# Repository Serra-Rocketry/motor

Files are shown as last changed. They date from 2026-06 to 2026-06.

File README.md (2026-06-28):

# Motor — Serra Rocketry

Desenhos CAD, especificações e dados de testes estáticos de motores de foguetes.

## Sobre

Este repositório contém a documentação técnica dos motores desenvolvidos pela equipe Serra Rocketry (IPRJ/UERJ). Aqui ficam os desenhos de peça, montagens, simulações OpenMotor e dados brutos de testes estáticos.

> **Nota:** O sistema de aquisição de dados (firmware, hardware, calibração) fica no repositório [thrust-stand](https://github.com/Serra-Rocketry/thrust-stand). Este repo armazena apenas os dados coletados e a documentação dos motores.

## Fronteira de Responsabilidade

Este repositório (`motor`) contém a **documentação da propulsão** e é a **fonte de verdade para geometria e dados brutos de motores**.

**Este repo contém:**
- Geometria do motor (CAD: .SLDPRT, .SLDASM, .SLDDRW, .STL, .STEP)
- Dados brutos de teste estático (.txt do SD card)
- Simulações OpenMotor (.ric)
- Gráficos simples de validação (thrust/pressão x tempo)
- Imagens e GIFs de testes
- Documentação técnica dos motores (.md)

**Este repo NÃO contém:**
- Análises sofisticadas de voo → [analysis](https://github.com/Serra-Rocketry/analysis)
- Biblioteca de motores (app web) → [analysis](https://github.com/Serra-Rocketry/analysis)
- Computador de bordo → [flight-computer](https://github.com/Serra-Rocketry/flight-computer)
- Simulações de trajetória → [analysis](https://github.com/Serra-Rocketry/analysis)

**Diagrama:**
```
[motor] ──dados brutos──→ [analysis] ──→ app web, biblioteca
   │                           │
   │ Propulsão                 │ Telemetria
   │ - Geometria               │ - Análise de testes
   │ - Dados SD card           │ - Simulações de voo
   │ - CAD                     │ - Visualização
   │ - OpenMotor (.ric)        │ - Biblioteca de motores
```

## Estrutura

```
docs/
├── static-tests/          # Dados de testes estáticos
│   ├── motor-gabriel/     # Dados SD + gráfico
│   ├── motor-caramelo/
│   ├── motor-i/
│   └── scilab/            # Projetos SciLab para análise
├── motors/                # Documentação por motor
│   ├── sr21000/           # Motor principal (2025)
│   ├── sr1500/            # Motor SR1500
│   ├── 300m/              # Motor 300M
│   ├── v1/                # Motor V1.0
│   └── cardboard/         # Motor de papelão
├── rockets/               # Foguetes (não apenas motores)
│   ├── 500m/              # Foguete de 500m
│   ├── 1000m/             # Foguete de 1km
│   └── commercial/        # Foguete comercial
├── molds/                 # Moldes para propelentes
├── tools/                 # Ferramentas e gabaritos
├── archive/               # Ideias experimentais não implementadas
├── imagens/               # Fotos, renderings, gráficos
└── training/              # Documentação de treinamento
```

## Competições

| Motor | Competição | Missão | Categoria | Ano | Resultado |
|---|---|---|---|---|---|
| SR21000 | [LASC 2025](https://www.lasc.space/past-events/6th-lasc) | SR Couto | 1 km – SRM | 2025 | 11º lugar, Major Damage |

## Como Usar

### Abrir arquivos CAD

Os arquivos `.SLDPRT` e `.SLDASM` são do SolidWorks. Se não tiver SolidWorks:

- Use o [eDrawings Viewer](https://www.solidworks.com/product/edrawings-viewer) (gratuito)
- Arquivos `.STEP` abrem em qualquer CAD (FreeCAD, Fusion 360, etc.)
- Arquivos `.STL` são para impressão 3D (slicer)

### Simulações OpenMotor

Arquivos `.ric` são do [OpenMotor](https://github.com/reilleya/openMotor), software livre de simulação de motores de foguete. Para abrir:

1. Instale o OpenMotor: `pip install openmotor` ou baixe o executável
2. Abra o arquivo `.ric` correspondente ao motor
3. Execute a simulação

### Dados de Teste

Os arquivos `.txt` em `static-tests/` contêm dados brutos do SD card no formato:

```
HH:MM:SS ; empuxo(kN) ; tempo(ms)
```

## Contribuindo

Este projeto segue as [Boas Práticas da Serra Rocketry](https://github.com/Serra-Rocketry/best-practices). Para contribuir:

1. Fork o projeto
2. Crie uma branch (`git checkout -b feature/nome`)
3. Commit suas mudanças
4. Abra um Pull Request

### Regras para Arquivos CAD

- Normalizar nomes: sem acentos, espaços → `_`
- SolidWorks 2024+ (compatível com versões anteriores)
- Incluir desenhos técnicos (`.SLDDRW`) quando disponível
- Exportar `.STEP` para interoperabilidade

## Links

- [Thrust Stand](https://github.com/Serra-Rocketry/thrust-stand) — Sistema de aquisição de dados
- [Ignitor](https://github.com/Serra-Rocketry/ignitor) — Sistema de ignição remota
- [Best Practices](https://github.com/Serra-Rocketry/best-practices) — Boas práticas da equipe
- [MIGRATION.md](./MIGRATION.md) — Histórico de migração do Drive

---

**Mantido por:** Equipe Serra Rocketry — IPRJ/UERJ

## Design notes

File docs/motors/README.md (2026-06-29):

# Motores

Documentação CAD e especificações dos motores desenvolvidos pela Serra Rocketry.

## Motores

| Motor | Status | Propulsante | Empuxo | Arquivos |
|---|---|---|---|---|
| [SR21000](./sr21000/) | Concluído | KNSU | 21000 Ns | CAD, desenhos, OpenMotor, STL, Parasolid |
| [SR1500](./sr1500/) | Concluído | KNSU | 1500 Ns | CAD, desenhos, OpenMotor, STL, gcode |
| [300M](./300m/) | Concluído | KNSU | — | CAD, STL, gcode |
| [V1](./v1/) | Concluído | KNSU | — | CAD |
| [Cardboard](./cardboard/) | Concluído | KNSU | — | CAD, STL (moldes) |

## Estrutura por motor

Cada motor pode ter as seguintes subpastas:

| Subpasta | Conteúdo | Software |
|---|---|---|
| `cad/` | Peças (`.SLDPRT`) e montagens (`.SLDASM`) | SolidWorks |
| `drawings/` | Desenhos técnicos (`.SLDDRW`, `.pdf`) | SolidWorks |
| `openmotor/` | Simulações (`.ric`) | [OpenMotor](https://github.com/reilleya/openMotor) |
| `stl/` | Modelos para impressão 3D (`.STL`) | Slicer |
| `parasolid/` | Modelos Parasolid (`.x_t`) | Interop CAD |
| `gcode/` | Instruções de impressão 3D (`.gcode`) | Slicer |

## Como abrir os arquivos

- **SolidWorks** (`.SLDPRT`, `.SLDASM`, `.SLDDRW`): SolidWorks 2024+ ou [eDrawings Viewer](https://www.solidworks.com/product/edrawings-viewer) (gratuito)
- **STEP** (`.step`, `.STEP`): qualquer CAD (FreeCAD, Fusion 360, SolidWorks)
- **STL** (`.STL`): qualquer slicer de impressão 3D
- **OpenMotor** (`.ric`): [OpenMotor](https://github.com/reilleya/openMotor) — software livre de simulação
- **Parasolid** (`.x_t`): SolidWorks, Fusion 360, ou qualquer CAD que suporte o formato

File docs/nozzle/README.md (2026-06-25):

# Nozzle de Cimento

Projeto do nozzle de cimento para motores de foguete.

## Arquivos

### CAD

| Arquivo | Descrição |
|---|---|
| [Base_Molde.SLDPRT](./cad/Base_Molde.SLDPRT) | Base do molde |
| [Meio_1_Molde.SLDPRT](./cad/Meio_1_Molde.SLDPRT) | Parte intermediária 1 |
| [Meio_2_Molde.SLDPRT](./cad/Meio_2_Molde.SLDPRT) | Parte intermediária 2 |
| [Topo_Molde.SLDPRT](./cad/Topo_Molde.SLDPRT) | Topo do molde |

### Montagem

| Arquivo | Descrição |
|---|---|
| [Montagem_Nozzle.SLDASM](./assembly/Montagem_Nozzle.SLDASM) | Montagem completa do nozzle |

### Cálculos

| Arquivo | Descrição |
|---|---|
| [calculo_nozzle.ipynb](./notebook/calculo_nozzle.ipynb) | Jupyter notebook com cálculos de nozzle |
| [passos_a_seguir.png](./passos_a_seguir.png) | Fluxograma de fabricação |

## Como usar

1. Abra os arquivos `.SLDPRT` no SolidWorks ou eDrawings
2. Para os cálculos, abra o notebook no Jupyter: `jupyter notebook calculo_nozzle.ipynb`

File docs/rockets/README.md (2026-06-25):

# Foguetes

Documentação CAD dos foguetes da Serra Rocketry.

## Foguetes

| Foguete | Altitude | Motor | Status | Arquivos |
|---|---|---|---|---|
| [500m](./500m/) | 500m | SR500M | Em desenvolvimento | CAD, STEP, montagem, OpenMotor |
| [1000m](./1000m/) | 1000m | SR1000M | Em desenvolvimento | CAD, STEP, montagem, OpenMotor |
| [Commercial](./commercial/) | — | — | — | CAD, STL, gcode |

## Estrutura por foguete

| Subpasta | Conteúdo |
|---|---|
| `cad/` | Peças (`.SLDPRT`) |
| `assembly/` | Montagens (`.SLDASM`) |
| `step/` | Modelos STEP para interoperabilidade |
| `parasolid/` | Modelos Parasolid (`.x_t`) |
| `simulation/` | Análises de simulação |
| `openmotor/` | Simulações do motor (`.ric`) |
| `mold/` | Moldes (`.step`) |

## Documentação

- [Documentação do foguete de 500m](./500m/documentation.md)
- [Documentação do foguete de 1km](./1000m/documentation.md)
- [Teste hidrostático do foguete de 500m](./500m/TESTE_HIDROSTATICO_500m_62bar.xls)

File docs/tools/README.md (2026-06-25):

# Ferramentas e Gabaritos

Ferramentas e gabaritos utilizados na fabricação de motores.

## Arquivos

### CAD

| Arquivo | Descrição |
|---|---|
| [Guia_Furo_Alma_Motor_De_Teste.SLDPRT](./cad/Guia_Furo_Alma_Motor_De_Teste.SLDPRT) | Guia para furo da alma do motor |

### STL (impressão 3D)

| Arquivo | Descrição |
|---|---|
| [Guia_Furo_Alma_Motor_De_Teste.STL](./stl/Guia_Furo_Alma_Motor_De_Teste.STL) | Guia para furo (imprimível) |

### G-code

| Arquivo | Material | Descrição |
|---|---|---|
| [CE3E3V2_Guia_Furo_Alma_Motor_De_Teste_PLA.gcode](./gcode/CE3E3V2_Guia_Furo_Alma_Motor_De_Teste_PLA.gcode) | PLA | Guia para furo |
| [CE3E3V2_Guia_Furo_Alma_Motor_De_Teste_PETG.gcode](./gcode/CE3E3V2_Guia_Furo_Alma_Motor_De_Teste_PETG.gcode) | PETG | Guia para furo |
| [Guia_Filamento_PLA.gcode](./gcode/Guia_Filamento_PLA.gcode) | PLA | Guia de filamento |

## Impressão 3D

Os arquivos `.gcode` são para impressora Ender 3 (CE3). Para usar em outra impressora, abra o `.STL` no seu slicer e gere o gcode correspondente.

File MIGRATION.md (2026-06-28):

# Migração do Drive para Git

## Origem

- **Fonte:** Google Drive, pasta "3-Propulsão"
- **Data da exportação:** 24/06/2026
- **Formato:** 3 arquivos ZIP (`3-Propulsão-20260624T230916Z-3-001.zip`, `-002`, `-003`)
- **Total:** ~5.4 GB, 390 arquivos
- **Backup local:** pasta `drive/` (não versionada, mantida como referência)

## Regras de Normalização

Nomes de arquivos e pastas foram normalizados para compatibilidade com Git:

- Acentos removidos: `ã→a`, `ç→c`, `é→e`, `ó→o`, `í→i`, `ú→u`
- Espaços → `_`
- Parênteses removidos
- Maiúsculas/minúsculas mantidas
- Exemplo: `Restrição_motor.SLDPRT` → `Restricao_motor.SLDPRT`

---

## Batch 1 — Estrutura e CAD (24/06/2026)

### Copiado

| Origem no Drive | Destino no Repo | Qtd |
|---|---|---|
| `Dados Testes Estático/Dados SDcard/MotorGabriel.txt` | `docs/static-tests/motor-gabriel/data.txt` | 1 |
| `Dados Testes Estático/Dados SDcard/MotorCaramelo.txt` | `docs/static-tests/motor-caramelo/data.txt` | 1 |
| `Dados Testes Estático/Gráficos/Motor I (69-31...).jpg` | `docs/static-tests/motor-i/empuxo_pressao.jpg` | 1 |
| `Dados Testes Estático/Gráficos/Motor Caramelo (65-35).jpg` | `docs/static-tests/motor-caramelo/empuxo_pressao.jpg` | 1 |
| `Dados Testes Estático/Gráficos/*.sciprj` | `docs/static-tests/scilab/` | 2 |
| `Motor SR1500/Componentes/` | `docs/motors/sr1500/cad/` | 8 |
| `Motor SR1500/Openmotor e Desenhos Técnicos/` | `docs/motors/sr1500/drawings/` | 3 |
| `Motor SR1500/Openmotor e Desenhos Técnicos/Motor SR1500.ric` | `docs/motors/sr1500/openmotor/` | 1 |
| `Motor SR1500/Componentes/GUIAALMA10MM.STL` | `docs/motors/sr1500/stl/` | 1 |
| `Motor SR1500/Componentes/CE3E3V2_GUIAALMA10MM.gcode` | `docs/motors/sr1500/gcode/` | 1 |
| `Motor SR1500/O_Ring .jpeg` | `docs/motors/sr1500/images/o_ring.jpg` | 1 |
| `SR21000/` (top-level CAD) | `docs/motors/sr21000/cad/` | 21 |
| `SR21000/Desenhos Tecnicos/` | `docs/motors/sr21000/drawings/` | 6 |
| `SR21000/*.ric` | `docs/motors/sr21000/openmotor/` | 3 |
| `SR21000/Inibidor/MoldeInibidor.STL` + `Fotos/Nozzle.STL` | `docs/motors/sr21000/stl/` | 2 |
| `SR21000/*.x_t` | `docs/motors/sr21000/parasolid/` | 3 |
| `SR21000/Inibidor/CE3E3V2_MoldeInibidor.gcode` | `docs/motors/sr21000/gcode/` | 1 |
| `SR21000/Molde Prensagem/` | `docs/motors/sr21000/cad/` | 2 |
| `SR21000/Fotos e Informações/*.jpg` | `docs/motors/sr21000/images/` | 2 |
| `SR21000/Fotos e Informações/captura*.png` | `docs/motors/sr21000/images/capturas/` | 4 |
| `SR21000/Teste Hidrostático/Gráfico_*.png` | `docs/motors/sr21000/images/` | 1 |
| `Motor SR21000 Inicial/` CAD | `docs/motors/sr21000-initial/cad/` | 4 |
| `Motor SR21000 Inicial/*.ric` | `docs/motors/sr21000-initial/openmotor/` | 2 |
| `Motor SR21000 Inicial/Fotos/` | `docs/imagens/sr21000-initial/` | 6 |
| `Dados e Testes Antigos/Motor 300M/` CAD | `docs/motors/300m/cad/` | 6 |
| `Dados e Testes Antigos/Motor 300M/*.STL` | `docs/motors/300m/stl/` | 2 |
| `Dados e Testes Antigos/Motor 300M/*.gcode` | `docs/motors/300m/gcode/` | 1 |
| `Dados e Testes Antigos/Motor V1.0/` CAD | `docs/motors/v1/cad/` | 4 |
| `Dados e Testes Antigos/Motor Papelão/` | `docs/motors/cardboard/` | 9 |
| `2026/Foguete 500M/` | `docs/rockets/500m/` | 10 |
| `2026/Foguete 1000M/` | `docs/rockets/1000m/` | 17 |
| `2025/Foguete Comercial/` | `docs/rockets/commercial/` | 3 |
| `2026/Molde/` | `docs/molds/` | 3 |
| `2025/Ideias/Molde Nozzle Cimento/` | `docs/nozzle/` | 9 |
| `2025/Ferramentas/` | `docs/tools/` | 6 |
| `2025/Código Nozzle/Calculo_Nozzle.ipynb` | `docs/nozzle/notebook/` | 1 |
| `2025/Código Nozzle/Passos a Seguir.png` | `docs/nozzle/` | 1 |

### docx → md (conversões)

| docx original | Destino |
|---|---|
| `Dimensões 1° motor.docx` | `docs/motors/v1/dimensoes.md` |
| `Tampa Motor.docx` | `docs/motors/v1/tampa_motor.md` |
| `Relatório SR21000.docx` | `docs/motors/sr21000/report.md` |
| `Anotações Caio.docx` | `docs/motors/sr21000/notes.md` |
| `Passos a Seguir Projeto SR 21000.docx` | `docs/motors/sr21000/next_steps.md` |
| `Materiais a ser utilizado.docx` | `docs/motors/sr21000-initial/materials.md` |
| `Pino_ParafusoSim-Análise estática 1-1.docx` | `docs/motors/sr21000/pin_analysis.md` |
| `Tubo-Teste De Pressão Interna Tubo-1.docx` | `docs/motors/sr21000/tube_pressure_test.md` |
| `Tubo-Análise estática 2-1.docx` | `docs/motors/sr21000/tube_analysis.md` |
| `Descrição Das Tarefas.docx` | `docs/training/task_description.md` |

### Ignorados (para processar depois)

| Item | Tamanho | Motivo | Próximo passo |
|---|---|---|---|
| `Eletrônica/` CAD | ~49 MB | Pertence ao thrust-stand | Mover para Serra-Rocketry/thrust-stand |
| `testeestatico/` STEP | ~0.1 MB | Bancada de teste, não motor | Vai para thrust-stand |
| Vídeos (.MOV/.MP4/.avi) | ~4.5 GB | Muito grandes para git | Batch 3: converter selecionados em GIFs |
| `.CWR` simulações | ~216 MB | Regeneráveis no SolidWorks | Ignorar permanentemente |
| `openMotor.exe` | 69 MB | Binário de terceiros | Ignorar (linkar download no README) |
| `.dmp`, `.err`, `.LOG`, `.MFC`, `.BMC`, `.BD2`, `.BDF`, `.PGF` | ~0.5 MB | Lixo de IDE/simulação | Ignorar permanentemente |
| `Reuniões/` (docx + png) | ~0.01 MB | Notas de reunião | ✅ Batch 2: convertido para md |
| `Fotos HEIC` (testes de queima, estufa) | ~44 MB | Formato Apple, precisa converter | Batch 3: converter para jpg |
| `Testes Propelente/` (docx + fotos + xlsx) | ~8.8 MB | Documentação de propelentes | ✅ Batch 2: copiado para propellants/ |
| `Dados Testes Estático/Dados SDcard/Motor6535.txt` | 34 B | Conteúdo: "Não Conseguimos Obter Os Dados :(" | Ignorar |
| `Dados Testes Estático/Dados SDcard/MotorÓxidoDeFerroeMagnésio.txt` | 31 B | Conteúdo: "Não Conseguimos Pegar Dados :(" | Ignorar |
| `SR21000/Teste Hidrostático/Mídias/` (vídeos) | ~340 MB | Vídeos de teste hidrostático | Batch 3: converter selecionados |
| `Motor SR21000 Inicial/` docx (relatório, anotações, etc.) | ~5 MB | Duplicata do SR21000 | Já copiado via SR21000 |
| `Fotos e Informações/Mont1.avi` | ~5 MB | Vídeo de montagem | Batch 3 |
| `Desenhos Tecnicos/*.PNG` (renderings) | ~0.3 MB | Imagens de referência | Já copiado em imagens/ |
| `.sciprj` (SciLab projects) | ~0.7 MB | Projetos SciLab | Já copiado em scilab/ |

---

## Batch 2 — Documentação restante (24/06/2026)

### docx → md

| docx original | Destino |
|---|---|
| `SR21000/Teste Hidrostático/Descrição do Teste.docx` | `docs/motors/sr21000/hydrostatic_test_description.md` |
| `Motor SR21000 Inicial/Simulações/Case do motor/Tubo-Teste De Pressão Interna Tubo-1.docx` | `docs/motors/sr21000-initial/tube_pressure_simulation.md` |
| `Testes Propelente/Teste Granulometria.../Descrição Do Teste.docx` | `docs/propellants/granulometry_test_description.md` |
| `Reuniões/Reunião Dia 09_08_2024.docx` | `docs/meetings/2024-08-09.md` |
| `Reuniões/Reunião 06_02_2026 (Caio e Italo).docx` | `docs/meetings/2026-02-06.md` |
| `2026/Foguete 1000M/Documentação.docx` | `docs/rockets/1000m/documentation.md` |
| `2026/Foguete 500M/Documentação do motor de 500m.docx` | `docs/rockets/500m/documentation.md` |
| `2026/Eletrônica/Ignitor/Funcionamento.docx` | `docs/ignitor/funcionamento.md` |
| `Teste De Queima 09-06-2023/Propelentes.docx` | `docs/propellants/teste_queima_2023-06-09.md` |
| `2026/Ideias.docx` | `docs/ideas.md` |

### Arquivos copiados

| Arquivo | Destino |
|---|---|
| `SR21000/Teste Hidrostático/*.xlsx` | `docs/motors/sr21000/TESTE_HIDROSTATICO_SR21000_88bar.xlsx` |
| `SR21000/Bulkhead_Sensor_Pressão.pdf` | `docs/motors/sr21000/drawings/Bulkhead_Sensor_Pressao.pdf` |
| `Foguete 500M/Teste Hidrostático/*.xls` | `docs/rockets/500m/TESTE_HIDROSTATICO_500m_62bar.xls` |
| `Teste De Queima/Dados Propelentes.xlsx` | `docs/propellants/dados_propelentes.xlsx` |
| `Teste Reprodutibilidade/*.xlsx` | `docs/propellants/teste_reprodutibilidade.xlsx` |
| `Teste estufa/planilha_teste_estufa.xlsx` | `docs/propellants/planilha_teste_estufa.xlsx` |
| `Ignitor/*.pdf` (fluxogramas) | `docs/ignitor/` |
| `Ignitor/README.md` | `docs/ignitor/README.md` |
| `Reunião Dia 16-05-2025/*.png` | `docs/meetings/images/` |
| `Reunião Dia 16-05-2025/*.ric` | `docs/meetings/` |
| `SR21000/Teste Hidrostático/Mídias/` (fotos) | `docs/motors/sr21000/images/hydrostatic/` |
| `Propelentes.jpeg` (foto) | `docs/propellants/photos/` |

### Novas pastas criadas

- `docs/propellants/` — documentação e dados de propelentes
- `docs/meetings/` — notas de reunião
- `docs/ignitor/` — documentação do ignitor (pertence ao thrust-stand)
- `docs/motors/sr21000/images/hydrostatic/` — fotos do teste hidrostático

---

## Batch 3 — GIFs de testes de queima (25/06/2026)

### Vídeos convertidos para GIF (320px, 8fps)

10 vídeos do teste de queima 09/06/2023 convertidos para GIF. Vídeos originais (~2.1 GB) mantidos apenas no `drive/`.

| Vídeo original | GIF | Tamanho |
|---|---|---|
| `Propelente 1 - 65% Nitrato 35% Açúcar.MOV` | `prop_1_knsu_padrao.gif` | 25 MB |
| `Propelente 2 - 65% Nitrato 35% Açúcar.MOV` | `prop_2_knsu_coroa.gif` | 13 MB |
| `Propelente 3 - 70% Nitrato 30% Açúcar.MOV` | `prop_3_knsu_70_30.gif` | 13 MB |
| `Propelente 4 - 50% Nitrato 50% Açúcar.MOV` | `prop_4_50_50.gif` | 32 MB |
| `Propelente 5 - 65% Nitrato 35% Dextrose.MOV` | `prop_5_knd.gif` | 13 MB |
| `Dextrose part 2.MOV` | `prop_5b_dextrose_part2.gif` | 4,5 MB |
| `Propelente 7 - ...CuFe2O4.MOV` | `prop_7_cufe2o4.gif` | 9,8 MB |
| `Propelente 8 - ...CoFe2O4.MOV` | `prop_8_cofe2o4.gif` | 20 MB |
| `Propelente 9 - ...NiFe2O4.MOV` | `prop_9_nife2o4.gif` | 14 MB |
| `Propelente 10 - ...ZnFe2O4.MOV` | `prop_10_znfe2o4.gif` | 14 MB |

**Total GIFs:** 155 MB (vs ~2.1 GB originais)

### Documentação atualizada

- `docs/propellants/teste_queima_2023-06-09.md` — reescrito com tabela, GIFs embutidos e links para dados
- Issue #1 criada: esclarecer diferença do Propelente 2 ("jeito do coroa")

### Vídeos ignorados (mantidos no drive/)

| Grupo | Tamanho | Motivo |
|---|---|---|
| Teste De Queima 10-07-2023 (5 vídeos) | ~560 MB | Sem nomes, sem documentação |
| Teste estufa (~35 vídeos) | ~1.9 GB | Sem nomes descritivos |
| Reunião OpenMotor.mp4 | 145 MB | Gravação de reunião |

## Batch 4 — Finalização (25/06/2026)

### READMEs criados

| Arquivo | Descrição |
|---|---|
| `docs/motors/README.md` | Visão geral dos motores e estrutura por motor |
| `docs/rockets/README.md` | Visão geral dos foguetes |
| `docs/propellants/README.md` | Documentação de propelentes e testes |
| `docs/static-tests/README.md` | Dados de testes estáticos e formato dos dados |
| `docs/nozzle/README.md` | Projeto do nozzle de cimento |
| `docs/tools/README.md` | Ferramentas e gabaritos |

### Revisão geral

- Estrutura verificada: 208 arquivos em 65 diretórios
- 27 arquivos Markdown (docs + READMEs)
- 11 simulações OpenMotor (.ric)
- Todos os nomes de arquivos normalizados
- `.gitignore` funcionando (drive/ não versionado)

---

## Status Final

| Batch | Commit | Arquivos | Conteúdo | Data |
|---|---|---|---|---|
| 1 | `b455cda` | 152 | Estrutura + CAD + test data | 24/06/2026 |
| 2 | `6f28990` | 46 | docx→md + planilhas + fotos | 24/06/2026 |
| 3 | `5bce81e` | 12 | GIFs de testes de queima | 25/06/2026 |
| 4 | — | 7 | READMEs + revisão | 25/06/2026 |
| **Total** | | **217** | | |

### Itens restantes no drive/ (não versionados)

| Item | Tamanho | Ação futura |
|---|---|---|
| Teste De Queima 10-07-2023 (5 vídeos) | ~560 MB | Ignorar (sem documentação) |
| Teste estufa (~35 vídeos) | ~1.9 GB | Ignorar (sem nomes) |
| Reunião OpenMotor.mp4 | 145 MB | Ignorar |
| Eletrônica/ CAD | ~49 MB | Mover para thrust-stand |
| testeestatico/ STEP | ~0.1 MB | Mover para thrust-stand |

### Próximos passos (opcional)

- Converter fotos HEIC → JPG (batch futuro, se necessário)
- Adicionar dados dos testes de queima 10-07-2023 quando documentação estiver disponível
- Mover arquivos de Eletrônica para o repositório thrust-stand

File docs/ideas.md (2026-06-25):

Ideias Para Propulsão - 2026

Motor:
Testar Diferentes tipos de acoplamento bulkhead/tubo nozzle/bulkhead;
Pesquisar outros tipos de vedação e etc;
Materiais diferentes;
Designs diferentes.

Propelente:
Novas composições (Nitrato+Eritritol, RNX, Nitrato+Açucar+aditivo, Nitrato+Sorbitol+Aditivo, …);
Testar outros métodos de fabricação;
Testar outras geometrias de alma (Teflon , Nylon);
Testar diferentes moldes e inibidores.

Skib (Testar ideia do gemini)

Eletrônicos:
Ignitor com sistema de acionamento seguro e de fácil uso;
Controle de temperatura com PID para panela;
Sensor de pressão made by serra rocketry;
Teste estático oficial;
Teste estático para motores pequenos;
Moinho de bolas com controle de velocidade e tempo.

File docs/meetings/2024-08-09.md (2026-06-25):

Reunião De Nivelamento Do Projeto

Tópicos Abordados:

Tarefas constantes do setor de propulsão
Comentar sobre o foco desse período 2024.2
Desenvolver motor para teste de propelente
Teste de armazenamento squib
Testes de novas composições para squib
Testes de novas composições de propelente (tarefa constante)
Inserção do propelente no OpenMotor
Aprofundar no estudo de nozzle

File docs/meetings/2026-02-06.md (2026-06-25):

Prioridades (Eletrônica):

Ignitor (Começar nas férias - Terminar até 10/04)
Fluxograma De Funcionamento (até 25/02)- Todos
Esquemático e Lista BOM (até 09/03)- ítalo, Steffany e Dias
Desenvolvimento do código (até 25/03)- Steffany e Dias
Protótipo e Teste (até 27/03)- ítalo e Joana
Montar a PCB (até 03/04)- Caio e Joana
Desenhar a case (até 10/04)- Ítalo
Imprimir a case e montar (até 15/04)- italo
Teste Final (até 17/04)- Todos

Teste Estático Motores Pequenos (Começar e terminar nas férias)
Verificar estrutura atual
Esquemático e Lista BOM
Ajustes no código
Estrutura para fixar os motores
Protótipo
Montar a PCB
Desenhar a case
Imprimir a case e montar

Teste Estático Motores Brutos ()
Verificar estrutura atual (Eletrônica) (Até 13/03)- Todos
Esquemático e Lista BOM (Até 20/03)-Ítalo e Dias
Ajustes no código (Até 27/03)- Steffany e Dias
Projeto Em CAD (Até 03/04)- Caio e Joana
Teste Eletrônica (Até 10/04)- Ítalo
Montar a PCB (Até 03/04)-Caio e joana
Desenhar a case (Até 10/04)- Caio
Imprimir a case e montar (Até 17/04)- Caio
Montar a Estrutura (Até 01/05)- Todos
Testar (Até 18/05)- Todos

Prioridades (Propulsão):

Segurança

Regras no lab de reações (Criar Regras)
Procedimento em testes e lançamentos (Criar Procedimentos)
Procedimentos de transporte e armazenamento de inflamáveis

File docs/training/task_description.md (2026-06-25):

Tarefa 1 :  Projetar um motor no OpenMotor com as configurações definidas abaixo.

O objetivo dessa tarefa é a compreensão dos parâmetros necessários para projetar um motor , tendo noção de qual parâmetro alterar para conseguir determinadas características como curva de empuxo, pressão máxima e etc .

*Manter os Parâmetros Grifados*

Configurações de Nozzle:

Configurações do Grão do Propelente:

Propelente utilizado :

Configurações Gerais:

O Que Precisa Fazer ??

Alterar os parâmetros livres , com o objetivo de obter o maior pico de empuxo e o maior impulso total sem extrapolar a pressão máxima de 700 Psi .

Tarefa 2 :  Projetar o motor estudado no OpenMotor em CAD
( Solidworks , FreeCAD , OnShape , …).

Data Limite :

Link SolidWorks Piratão :

magnet:?xt=urn:btih:3AC3CC164166C96B95B1288627EAA089F8B530AC&dn=SolidWorks+2023+SP5+Full+Premium+%28x64%29+-+%5BhaxNode%5D&tr=http%3A%2F%2Fp4p.arenabg.com%3A1337%2Fannounce&tr=udp%3A%2F%2F47.ip-51-68-199.eu%3A6969%2Fannounce&tr=udp%3A%2F%2F9.rarbg.me%3A2780%2Fannounce&tr=udp%3A%2F%2F9.rarbg.to%3A2710%2Fannounce&tr=udp%3A%2F%2F9.rarbg.to%3A2730%2Fannounce&tr=udp%3A%2F%2F9.rarbg.to%3A2920%2Fannounce&tr=udp%3A%2F%2Fopen.stealth.si%3A80%2Fannounce&tr=udp%3A%2F%2Fopentracker.i2p.rocks%3A6969%2Fannounce&tr=udp%3A%2F%2Ftracker.coppersurfer.tk%3A6969%2Fannounce&tr=udp%3A%2F%2Ftracker.cyberia.is%3A6969%2Fannounce&tr=udp%3A%2F%2Ftracker.dler.org%3A6969%2Fannounce&tr=udp%3A%2F%2Ftracker.internetwarriors.net%3A1337%2Fannounce&tr=udp%3A%2F%2Ftracker.leechers-paradise.org%3A6969%2Fannounce&tr=udp%3A%2F%2Ftracker.openbittorrent.com%3A6969%2Fannounce&tr=udp%3A%2F%2Ftracker.opentrackr.org%3A1337&tr=udp%3A%2F%2Ftracker.pirateparty.gr%3A6969%2Fannounce&tr=udp%3A%2F%2Ftracker.tiny-vps.com%3A6969%2Fannounce&tr=udp%3A%2F%2Ftracker.torrent.eu.org%3A451%2Fannounce

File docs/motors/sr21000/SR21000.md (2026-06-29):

# Motor SR21000

**Equipe:** Serra Rocketry — IPRJ/UERJ  
**Classificação:** I254  
**Status:** Concluído

---

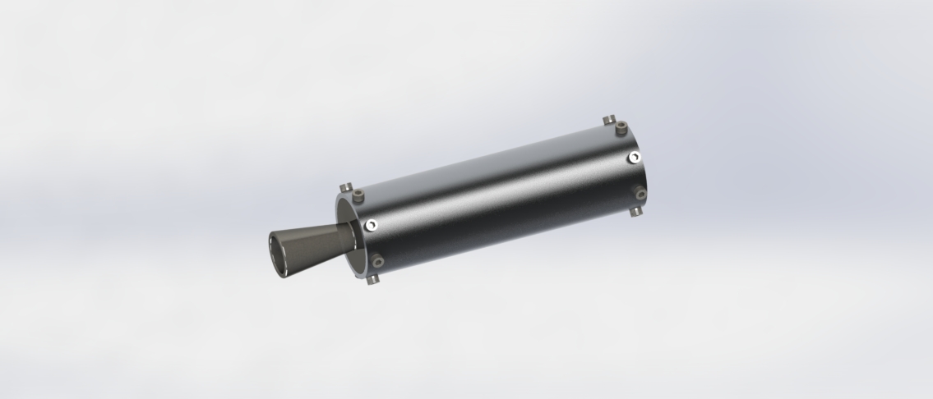
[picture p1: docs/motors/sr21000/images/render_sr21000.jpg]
Render do motor SR21000


O SR21000 é o motor principal da Serra Rocketry, projetado para atingir alturas na faixa de 1000 metros com foguetes de médio porte. Batizado em homenagem ao laboratório do IPRJ, este motor representa a evolução de anos de experimentos com propelentes sólidos — desde os primeiros grãos de KNSU caseiros até um projeto completo, simulado, fabricado, testado e最终mente levado ao voo.

Este documento conta a história completa do SR21000: como surgiu a ideia, como foi simulado no OpenMotor, como cada peça foi projetada e fabricada, como o motor se comportou sob pressão no teste hidrostático, e como ele se saiu no seu primeiro (e único) voo.

---

## Sumário

1. [Simulação OpenMotor](#simulação-openmotor)
2. [Projeto e Materiais](#projeto-e-materiais)
3. [Teste Hidrostático](#teste-hidrostático)
4. [Teste Estático](#teste-estático)
5. [Voo](#voo)
6. [Arquivos do Projeto](#arquivos-do-projeto)
7. [Dados Faltando](#dados-faltando)

---

## Simulação OpenMotor

Todo motor de foguete sólido começa no papel — ou melhor, no software. Antes de cortar qualquer tubo de alumínio ou fundir propelente, precisávamos responder perguntas fundamentais: quanto de empuxo esse motor vai gerar? Qual vai ser a pressão máxima dentro da câmara? O nozzle vai suportar?

Usamos o [OpenMotor](https://github.com/reilleya/openMotor), um software de simulação de motores de foguete sólidos, para responder essas perguntas. Duas simulações foram realizadas com propelente **Nakka KNSU** (65% KNO₃ + 35% Sacarose), utilizando os parâmetros de taxa de queima do próprio Nakka:

| Parâmetro | Valor |
|---|---|
| Coeficiente de queima (a) | 0.0001007 |
| Expoente de pressão (n) | 0.319 |
| Razão de calores específicos (k) | 1.133 |
| Temperatura de combustão (T) | 1720 K |
| Densidade do propelente | 1800 kg/m³ |

### Configuração do Grão

O grão de propelente segue a configuração **BATES** (Bulkhead Assembly with Throat and End Segments), que é o padrão para motores amadores de médio porte:

| Parâmetro | Valor |
|---|---|
| Tipo | BATES |
| Diâmetro externo | 44 mm |
| Diâmetro do core | 10 mm |
| Comprimento | 110 mm |
| Extremidades inibidas | Não |

### Da Ideia Inicial à Configuração Final

A primeira simulação — chamada "Ideia Inicial" — representava nosso chute inicial: um nozzle com throat de 8 mm e exit de 14 mm, com ângulos de convergência e divergência que seguiam referências da literatura. Mas quando analisamos os resultados, percebemos que precisávamos de mais empuxo e uma expansão mais eficiente dos gases.

A configuração final, batizada de "Nozzle SR21000", trouxe mudanças significativas:

| Parâmetro | Ideia Inicial | Nozzle SR21000 |
|---|---|---|
| Throat | 8.00 mm | 9.92 mm |
| Exit | 14.00 mm | 28.00 mm |
| Ângulo convergente | 20° | 30° |
| Ângulo divergente | 17° | 17° |

O throat maior (9.92 mm) permite uma taxa de queima mais controlada, enquanto o exit quase o dobro (28 mm) aumenta significativamente a razão de expansão — de 3.06 para 7.91 — resultando em melhor aproveitamento da energia dos gases de exaustão.

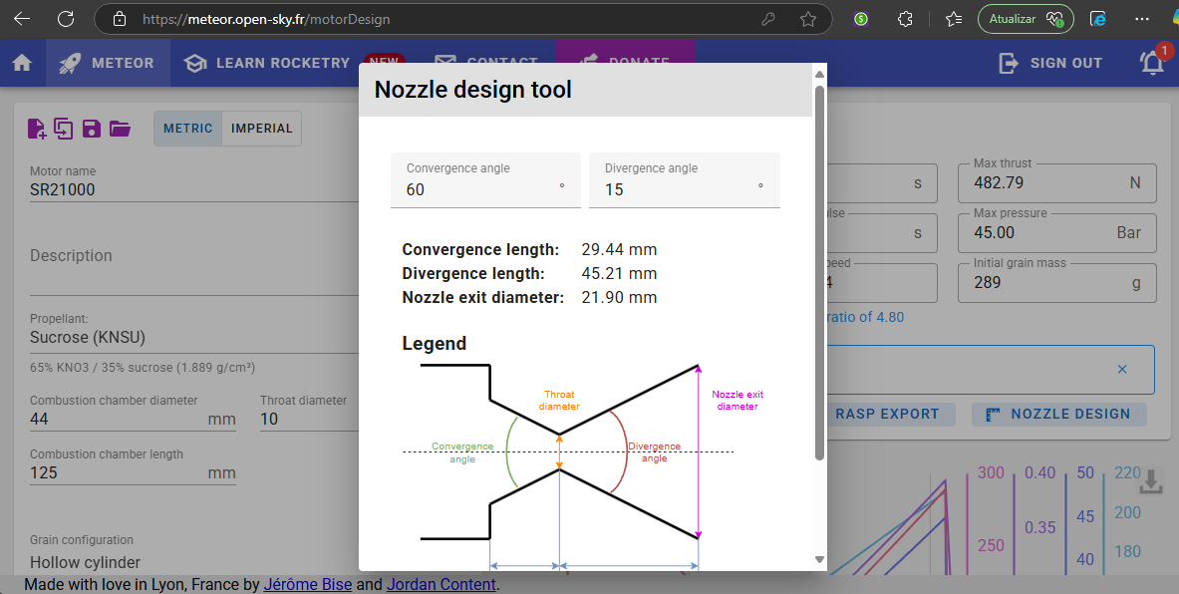
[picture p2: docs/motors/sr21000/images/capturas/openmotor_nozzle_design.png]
OpenMotor — design do nozzle


*Geometria do nozzle na simulação: seção convergente (30°), gargalo de 9.92 mm e seção divergente (17°) expandindo até 28 mm.*

### Resultados da Simulação Final

A simulação do "Nozzle SR21000" produziu os seguintes resultados:

| Parâmetro | Valor |
|---|---|
| Classificação | I254 |
| Empuxo máximo | 482.79 N |
| Impulso total | 340.95 Ns |
| Impulso específico (Isp) | 120.15 s |
| Pressão máxima | 45.00 bar |
| Pressão média | 25.34 bar |
| Tempo de queima | 1.34 s |
| Velocidade de saída | Mach 2.64 |
| Razão de expansão | 4.80 |
| Massa do grão | 289 g |

Esses números contam uma história interessante: um motor compacto, com menos de 1.1 kg no total, capaz de gerar quase 50 kg de força por mais de um segundo. A pressão máxima de 45 bar ficou bem dentro dos limites seguros para um case de alumínio — mas precisávamos confirmar isso com um teste real.

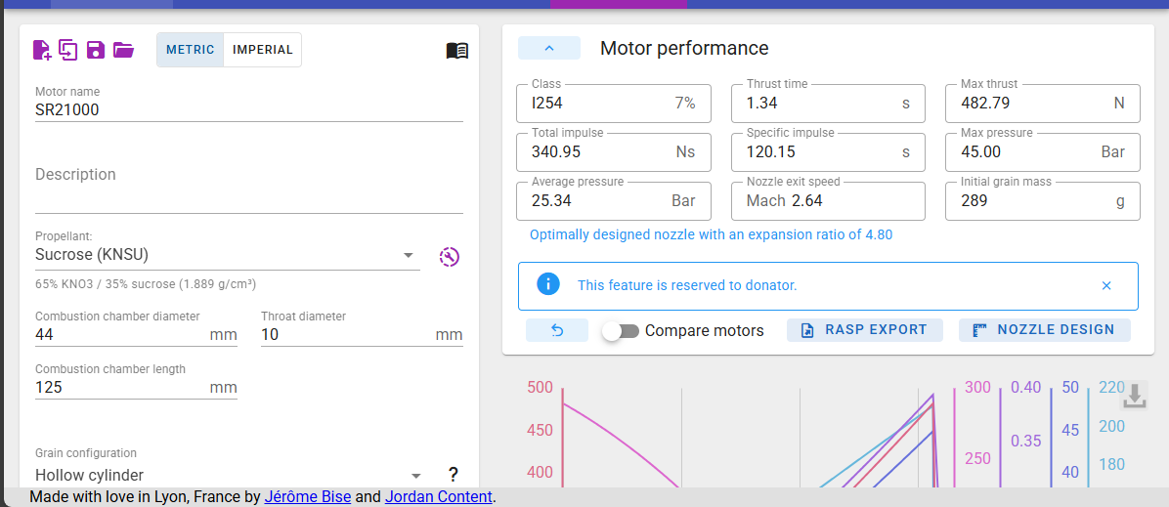
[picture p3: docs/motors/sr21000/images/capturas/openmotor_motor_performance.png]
OpenMotor — performance do motor


*Visão geral do desempenho: impulso específico, eficiência do nozzle e parâmetros de combustão.*

### Curvas de Desempenho

As simulações geraram gráficos detalhados da evolução do motor durante a queima:

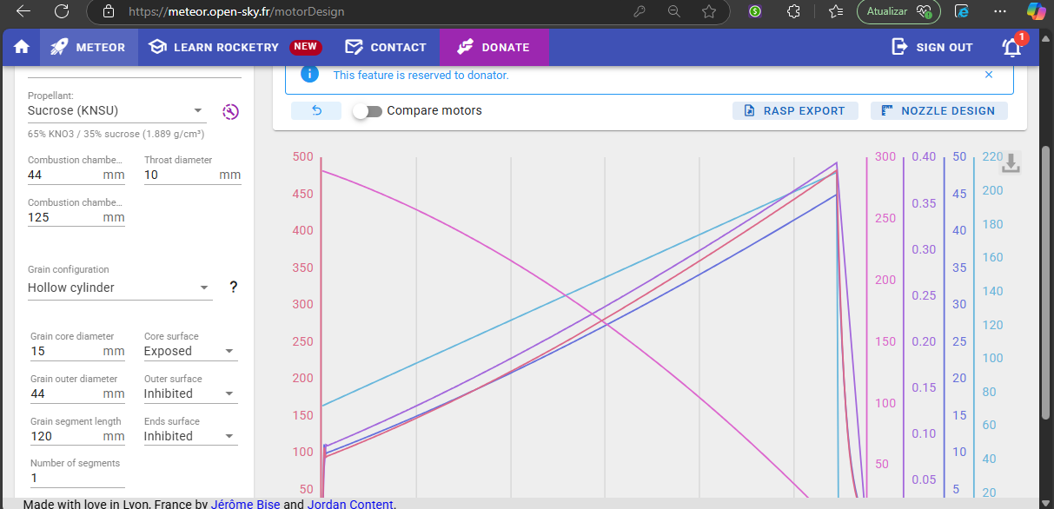
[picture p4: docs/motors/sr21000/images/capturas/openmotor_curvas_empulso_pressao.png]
OpenMotor — curvas de empuxo e pressão


*Curvas de empuxo (azul) e pressão na câmara (rosa) ao longo do tempo. Note como a pressão atinge o pico rapidamente e depois cai conforme o propelente é consumido, enquanto o empuxo mantém-se relativamente estável durante a queima principal.*

**Arquivos de simulação:**
- [`openmotor/nozzle_sr21000.ric`](./openmotor/nozzle_sr21000.ric) — Configuração final (throat 9.92 mm)
- [`openmotor/Ideia_Inicial_SR21000.ric`](./openmotor/Ideia_Inicial_SR21000.ric) — Configuração inicial (throat 8 mm)
- [`openmotor/SR21000_KNSB_150mm.ric`](./openmotor/SR21000_KNSB_150mm.ric) — Simulação alternativa com KNSB
- [`openmotor/SR21000_KNSB_275mm.ric`](./openmotor/SR21000_KNSB_275mm.ric) — Simulação alternativa com KNSB

---

## Projeto e Materiais

Com os resultados da simulação em mãos, partimos para a parte física: como transformar esses números em uma peça de metal que aguenta 45 bar de pressão e 1720 K de temperatura? Cada componente do SR21000 foi projetado levando em consideração três fatores: segurança, fabricabilidade e custo.

### Case (Tubo)

O tubo da câmara de combustão é a espinha dorsal do motor. Ele precisa conter a pressão interna, suportar os esforços de fixação do nozzle e da tampa, e resistir ao calor durante a queima.

Escolhemos **alumínio 6063-T5** — uma liga comum na indústria, disponível em qualquer casa de metais, fácil de usinar e com excelente relação peso/resistência. Titânio e aço 1045 foram considerados, mas descartados: titânio seria ideal em peso, mas o custo era proibitivo; aço 1045 seria mais barato, mas o peso extra não compensava.

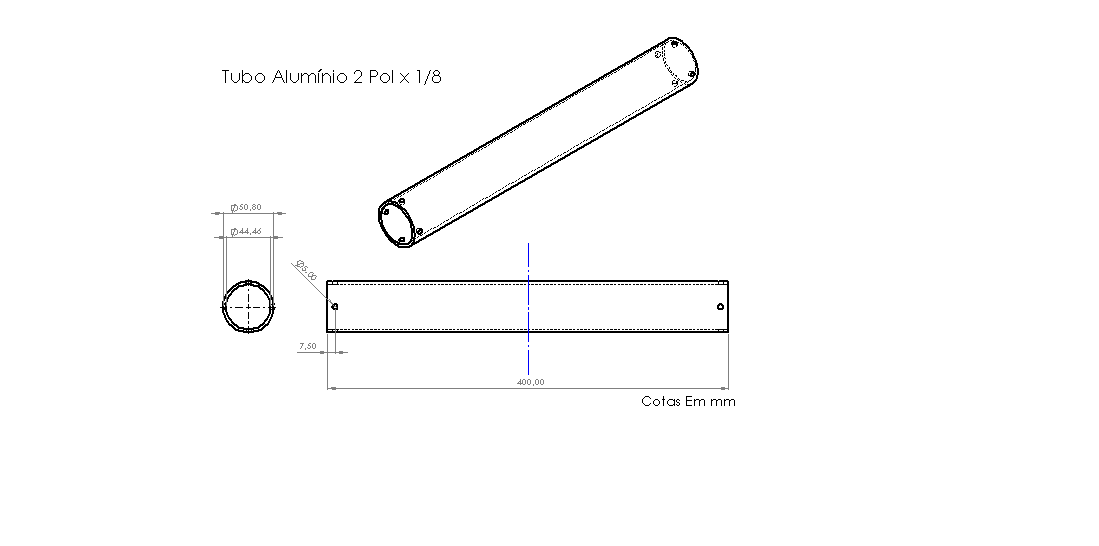
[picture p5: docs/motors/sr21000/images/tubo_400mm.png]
Tubo — desenho técnico


*Desenho técnico do tubo de alumínio 6063-T5, mostrando as cotas principais e o furo de fixação para o sistema de sustentação.*

| Dimensão | Valor |
|---|---|
| Diâmetro externo | 50.80 mm (2") |
| Diâmetro interno | 44.46 mm |
| Espessura da parede | 3.17 mm (1/8") |
| Comprimento | 400 mm |
| Furo de fixação | Ø25.00 mm |

**Arquivos CAD:**
- [`cad/Tubo.SLDPRT`](./cad/Tubo.SLDPRT)
- [`cad/Secao_Tubo.SLDPRT`](./cad/Secao_Tubo.SLDPRT)
- [`drawings/Tubo_400mm.SLDDRW`](./drawings/Tubo_400mm.SLDDRW)

### Tampa (Bulkhead)

A tampa — ou bulkhead — é responsável por vedar a extremidade superior do motor e fornecer o ponto de fixação para o sistema de ignição. Ela precisa ser leve o suficiente para não comprometer o empuxo, mas resistente o suficiente para suportar a pressão interna sem deformar.

O design da bulkhead passou por iterações até chegarmos à versão final, com otimização para distribuição de parafusos e vedação por O'Ring:

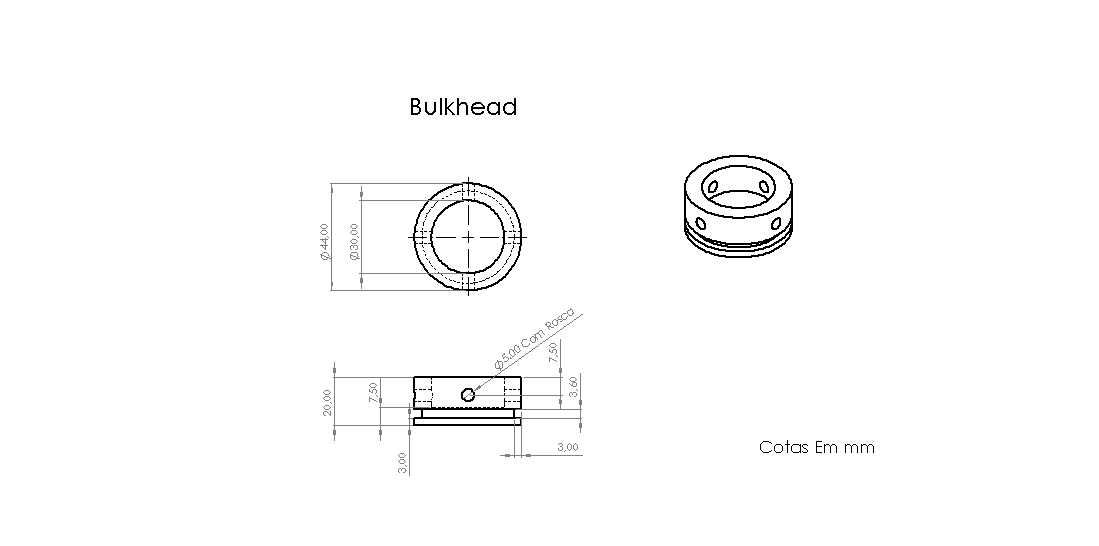
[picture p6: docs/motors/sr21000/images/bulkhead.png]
Bulkhead — desenho técnico


*Detalhe da bulkhead v2, mostrando a rosca central para o sensor de pressão e o padrão de furos para fixação.*

| Dimensão | Valor |
|---|---|
| Diâmetro externo | 44.00 mm |
| Diâmetro do círculo de furos | 30.00 mm |
| Furo central | Ø5.00 mm (com rosca) |
| Altura total | 20.00 mm |
| Altura do corpo principal | 7.50 mm |
| Altura da base | 3.00 mm |

**Arquivos CAD:**
- [`cad/Bulkhead.SLDPRT`](./cad/Bulkhead.SLDPRT)
- [`cad/BulkheadV2.SLDPRT`](./cad/BulkheadV2.SLDPRT)
- [`drawings/BulkheadV2_-_Copia.SLDDRW`](./drawings/BulkheadV2_-_Copia.SLDDRW)
- [`drawings/Bulkhead_Sensor_Pressao.pdf`](./drawings/Bulkhead_Sensor_Pressao.pdf)

### Nozzle

O nozzle é talvez a peça mais crítica de todo o motor. Ele converte a energia térmica dos gases de exaustão em impulsão mecânica — e o formato dele define a eficiência de toda a conversão. Um nozzle mal projetado pode desperdiçar energia, causar erosão excessiva, ou até provocar instabilidades na queima.

O nozzle do SR21000 foi projetado em **aço 1020**, escolhido pela sua resistência mecânica, boa usinabilidade e custo acessível. A geometria segue o modelo de De Laval clássico: seção convergente, gargalo e seção divergente.

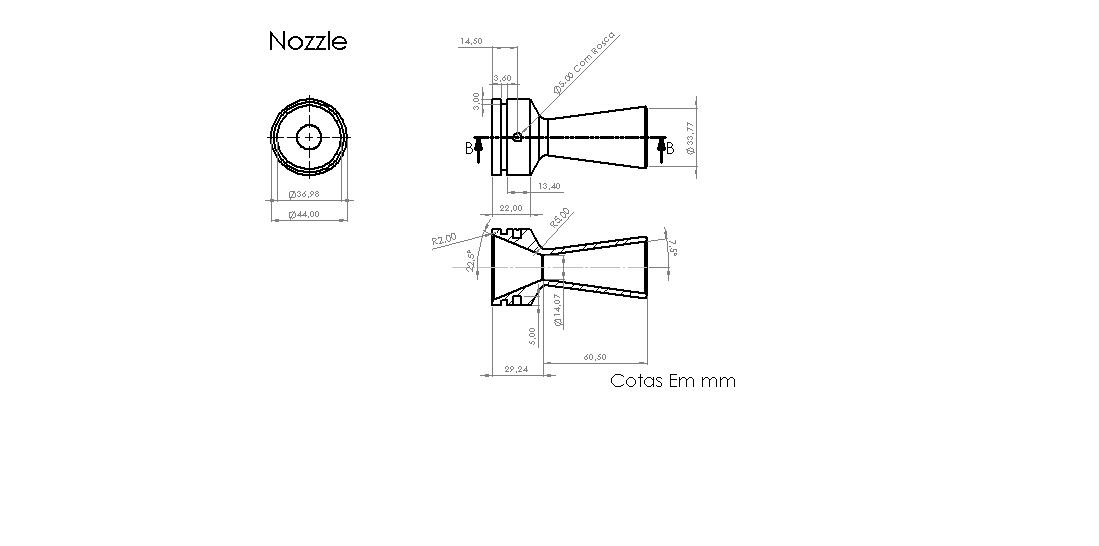
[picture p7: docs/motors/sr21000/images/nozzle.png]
Nozzle — desenho técnico


*Desenho técnico do nozzle, com detalhe das roscas de fixação e da geometria de De Laval.*

| Dimensão | Valor |
|---|---|
| Comprimento total | 60.60 mm |
| Diâmetro externo (base) | 44.00 mm |
| Diâmetro externo (com roscas) | 39.00 mm |
| Diâmetro de saída | 33.77 mm |
| Diâmetro interno | 14.07 mm |
| Ângulo convergente | 2.5° |
| Ângulo divergente | 22.5° |
| Comprimento da seção cônica | 22.00 mm |
| Comprimento da seção cilíndrica | 13.40 mm |
| Espessura da parede (base) | 3.60 mm |
| Altura do flange traseiro | 3.00 mm |
| Raio interno frontal | R2.00 mm |
| Raio interno traseiro | R2.50 mm |

**Arquivos CAD:**
- [`cad/Nozzle.SLDPRT`](./cad/Nozzle.SLDPRT)
- [`drawings/Nozzle.SLDDRW`](./drawings/Nozzle.SLDDRW)
- [`stl/Nozzle.STL`](./stl/Nozzle.STL)
- [`parasolid/Nozzle_14mmThroat.x_t`](./parasolid/Nozzle_14mmThroat.x_t)

### Inibidor

O inibidor é uma peça simples, mas essencial: ele controla a geometria do grão de propelente, definindo onde a queima começa e como ela se propaga. Feito de **papelão**, é barato, leve e fácil de fabricar — perfeito para protótipos e testes iniciais.

**Arquivos CAD:**
- [`cad/Inibidor_Papelao.SLDPRT`](./cad/Inibidor_Papelao.SLDPRT)
- [`cad/Inibidor.SLDPRT`](./cad/Inibidor.SLDPRT)
- [`stl/MoldeInibidor.STL`](./stl/MoldeInibidor.STL)

### Fixação

A fixação dos componentes entre si é tão importante quanto as peças individualmente. Um parafuso que falha ou um O'Ring que vaza pode ser catastrófico.

| Componente | Especificação |
|---|---|
| Parafusos | 16× M5 inox |
| O'Rings | 8× 2-131 (W=2.62 mm, D.I.=42.52 mm) |

### Especificações Gerais

| Parâmetro | Valor |
|---|---|
| Massa do motor vazio | 724 g (0.724 kg) |
| Massa do motor cheio | 1054 g (1.054 kg) |
| Pressão de trabalho (case) | 500 PSI |
| Fator de segurança | 2.5 |
| Pressão simulada (case) | 1250 PSI (86.2 bar) |
| Força na tampa (simulada) | 13.108 N |
| Densidade do propelente | 1.889 g/cm³ |

---

## Teste Hidrostático

Simulações são importantes, mas nada substitui um teste real. O teste hidrostático é o momento da verdade: submeter o motor a pressões crescentes até o limite — ou além — para validar a integridade estrutural do case, das vedações e de todos os componentes.

### Objetivo

O objetivo principal era validar se o case de alumínio 6063-T5, com 3.17 mm de espessura, suportaria a pressão máxima simulada de 86.2 bar (1250 PSI) com fator de segurança 2.5. Para isso, decidimos levar o motor até **90 bar** — uma margem de segurança adicional.

### Procedimento

O teste foi realizado em **26 de agosto de 2025**, no laboratório do IPRJ. A montagem incluiu:

- **Bomba Haskel** com válvula Flutrol para controle preciso de pressão
- **Transdutor de pressão calibrado** para medição em tempo real
- **Painel de controle elétrico** com interruptores e indicadores
- **Sistema de monitoramento** com laptop e câmeras de segurança
- **Suporte de madeira** para fixar o motor durante o teste

O procedimento seguiu três etapas:

1. **Preparação**: Montagem do motor no suporte, conexão da bomba, calibração do transdutor
2. **Execução**: Subida gradual de pressão, monitoramento constante, registro de dados
3. **Análise**: Verificação de vazamentos, inspeção visual, análise dos dados coletados

### Resultados

O teste durou aproximadamente 17 minutos, com a pressão atingindo seu pico às 12:13:18:

| Parâmetro | Valor |
|---|---|
| Data | 26/08/2025 |
| Pressão máxima atingida | 89.8 bar |
| Horário do pico | 12:13:18 |
| Duração total | ~17 min |
| Pressão de início da subida (>50 bar) | 12:12:05 |

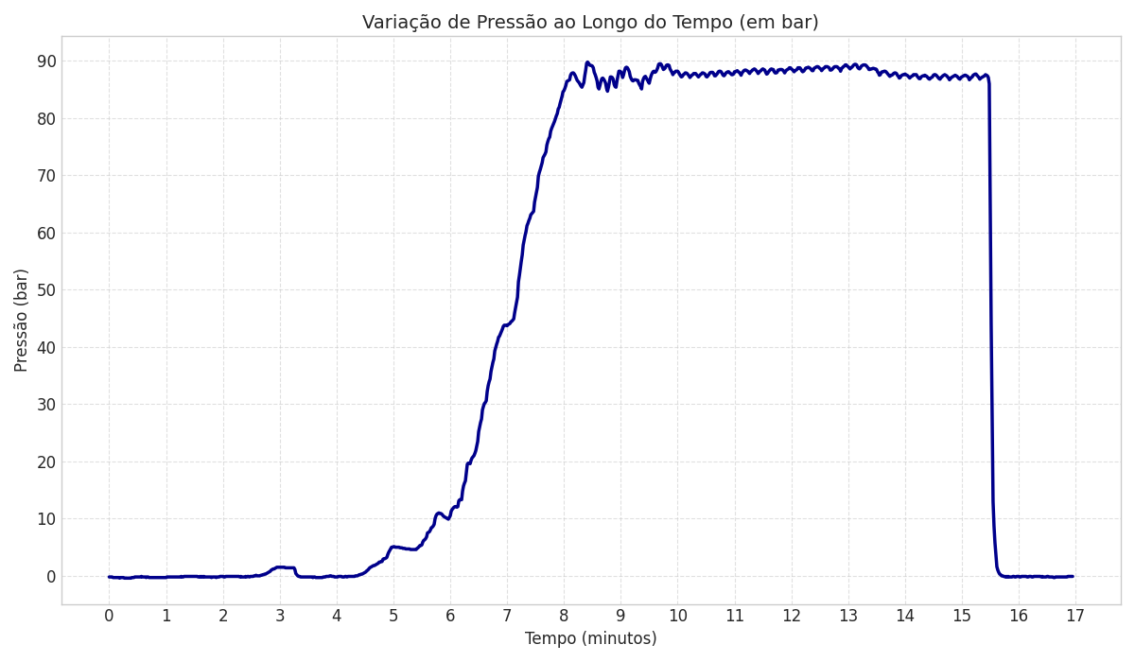
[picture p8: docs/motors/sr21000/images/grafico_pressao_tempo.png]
Pressão x tempo — teste hidrostático


*Gráfico de pressão x tempo do teste hidrostático. A subida principal ocorreu entre 12:12:05 e 12:13:18, com pico de 89.8 bar — acima dos 86.2 bar simulados, validando a margem de segurança.*

O resultado foi animador: o case suportou **89.8 bar** sem nenhuma deformação visível ou vazamento. A pressão ficou acima dos 86.2 bar simulados com fator de segurança 2.5, confirmando que o projeto estrutural está sólido.

### Fotos do Teste

<table>
<tr>
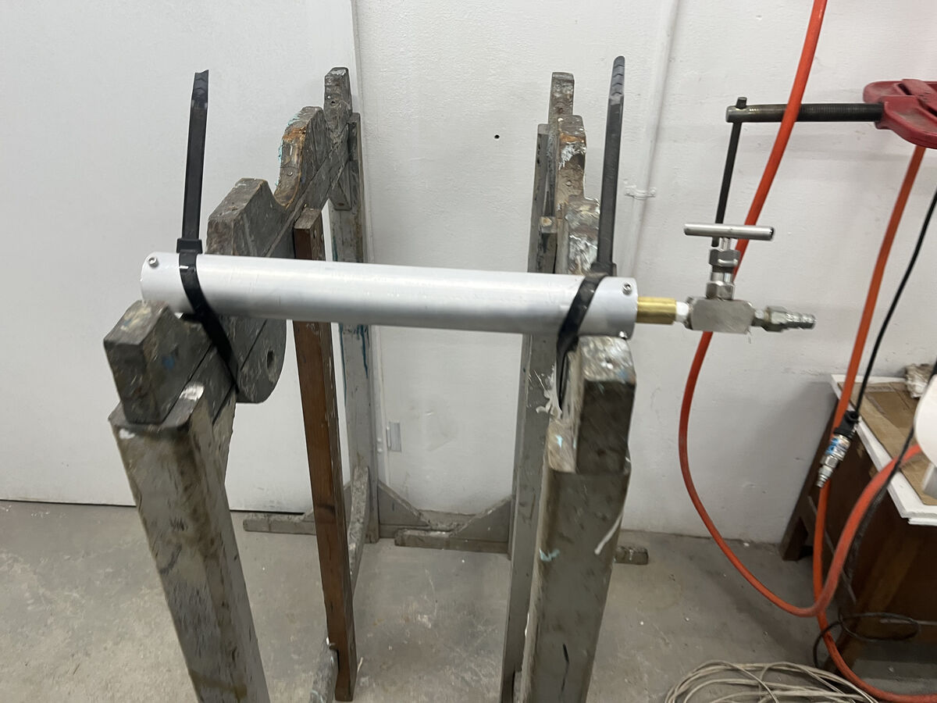
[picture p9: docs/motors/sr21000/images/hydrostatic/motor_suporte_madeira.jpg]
<td><br>Motor fixado no suporte de madeira, pronto para o teste</td>
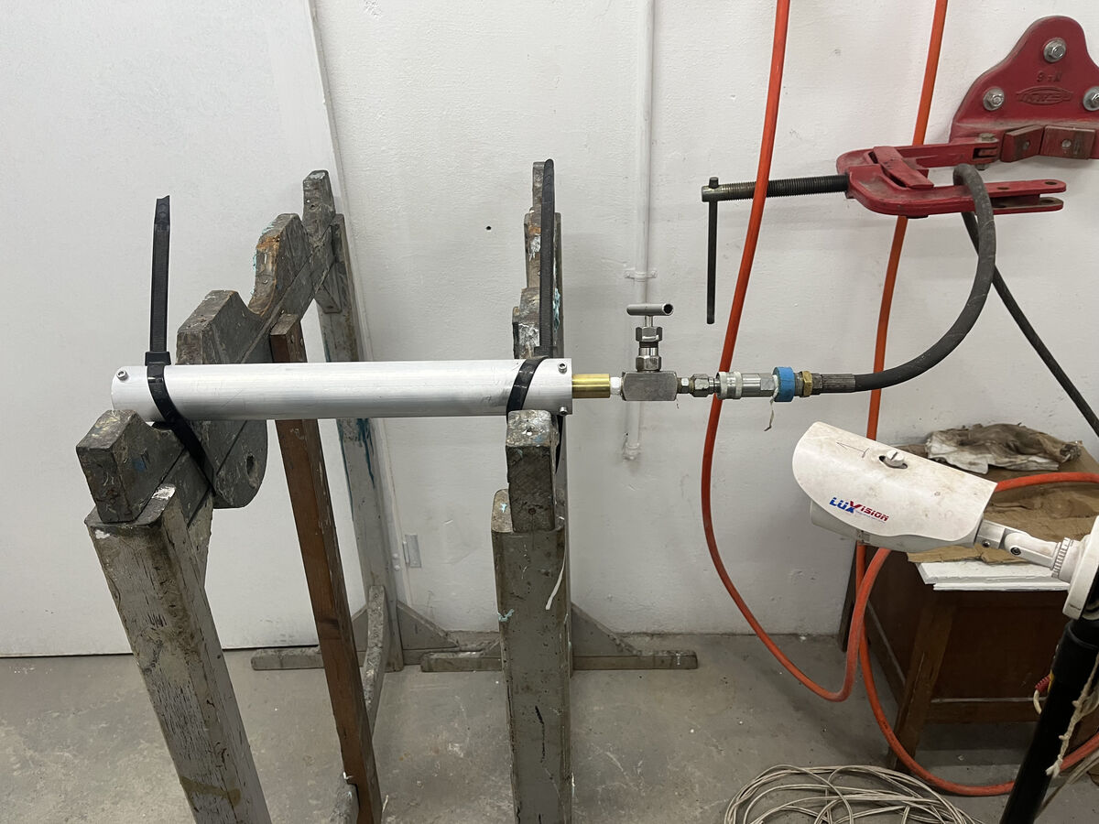
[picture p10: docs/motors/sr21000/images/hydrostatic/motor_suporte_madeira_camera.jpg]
<td><br>Suporte com câmera de segurança para monitoramento remoto</td>
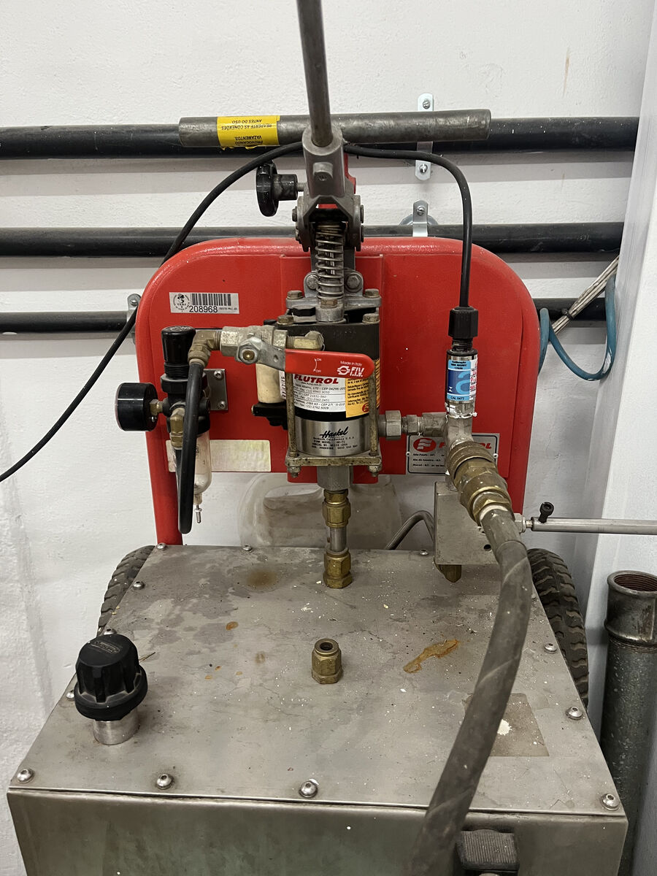
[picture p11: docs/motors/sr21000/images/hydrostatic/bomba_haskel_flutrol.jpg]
<td><br>Bomba Haskel com válvula Flutrol para controle preciso de pressão</td>
</tr>
<tr>
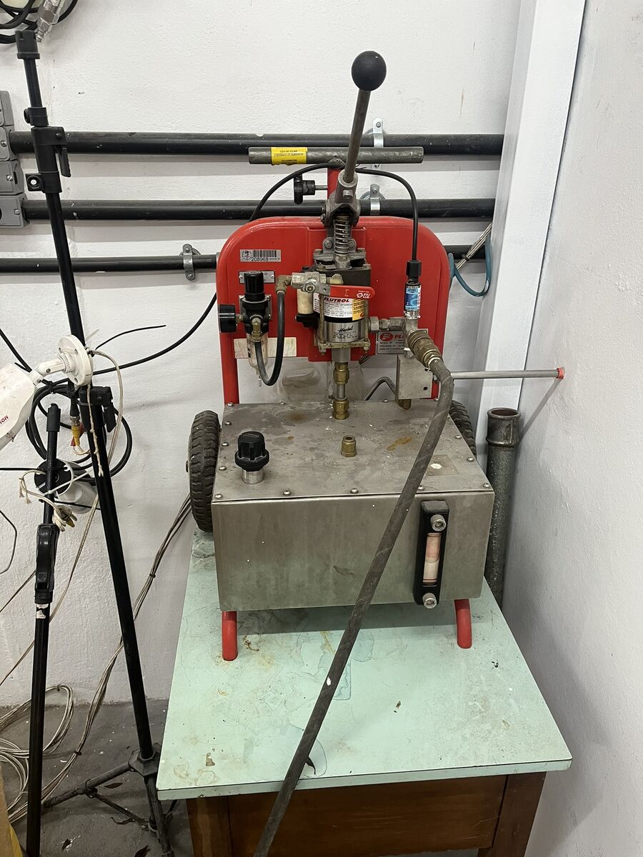
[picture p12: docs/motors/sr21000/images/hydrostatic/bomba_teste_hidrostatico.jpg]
<td><br>Detalhe da bomba utilizada no teste</td>
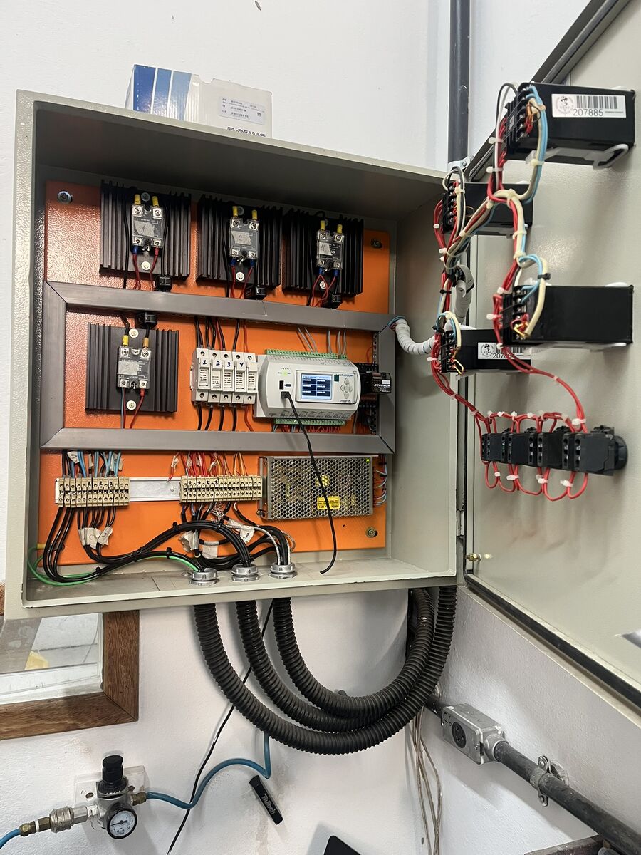
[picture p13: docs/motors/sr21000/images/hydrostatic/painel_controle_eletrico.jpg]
<td><br>Painel de controle elétrico com interruptores e indicadores</td>
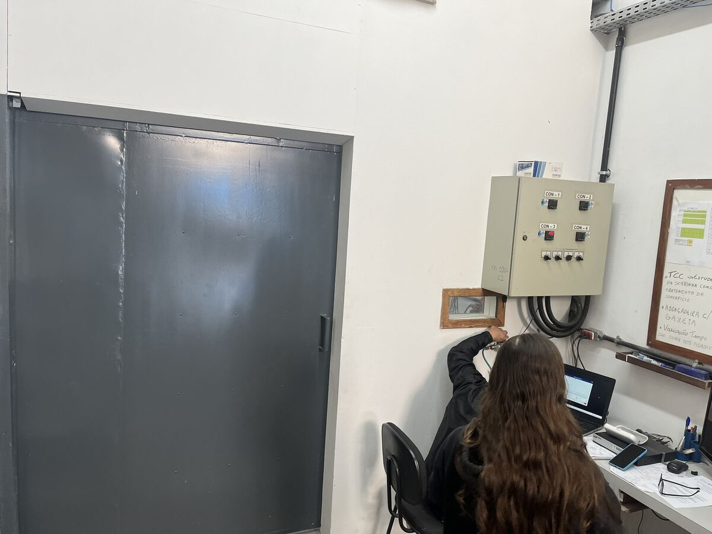
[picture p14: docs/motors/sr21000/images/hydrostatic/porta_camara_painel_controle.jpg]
<td><br>Visão geral da câmara de teste e painel</td>
</tr>
<tr>
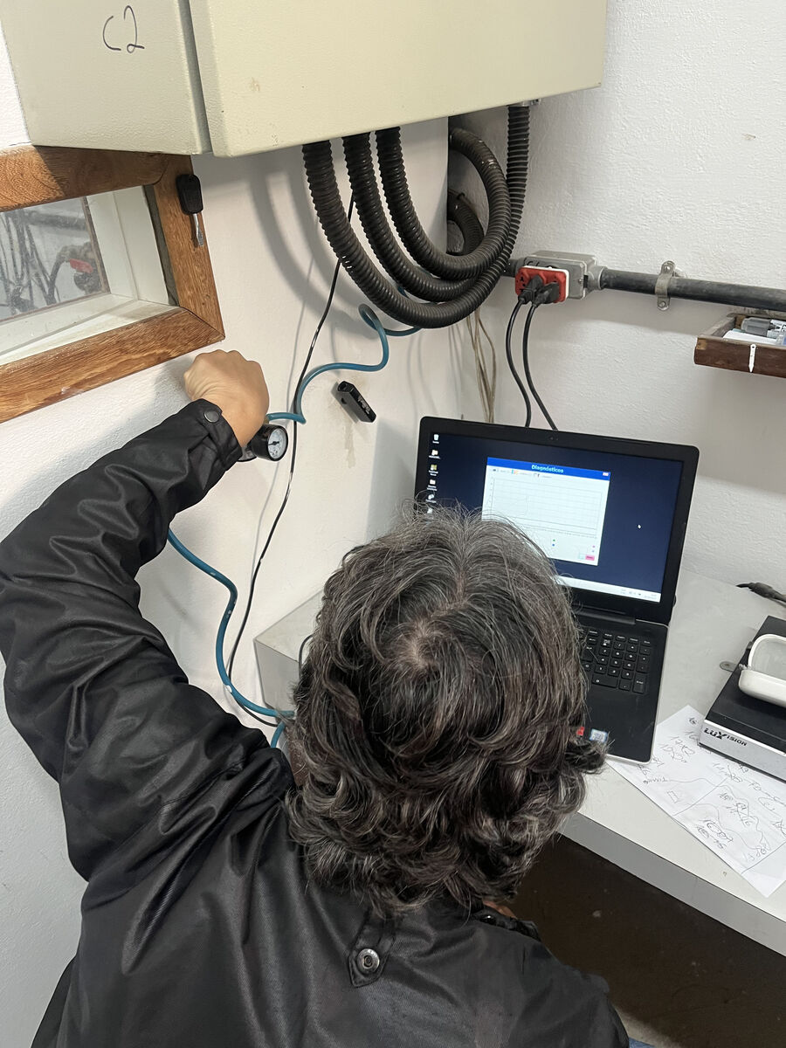
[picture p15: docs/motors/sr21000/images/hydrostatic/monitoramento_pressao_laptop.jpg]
<td><br>Monitoramento de pressão em tempo real no laptop</td>
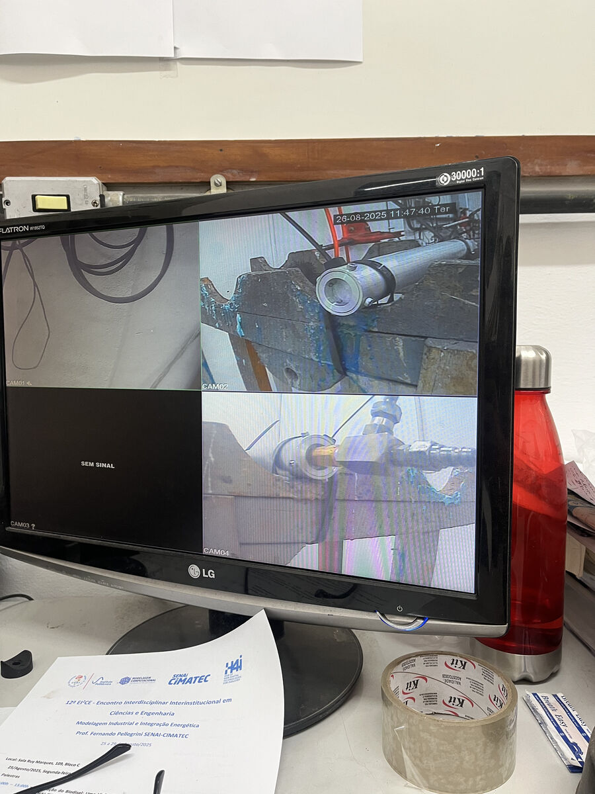
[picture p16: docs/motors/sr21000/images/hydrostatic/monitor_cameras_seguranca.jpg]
<td><br>Monitor de câmeras de segurança — observação remota durante o teste</td>
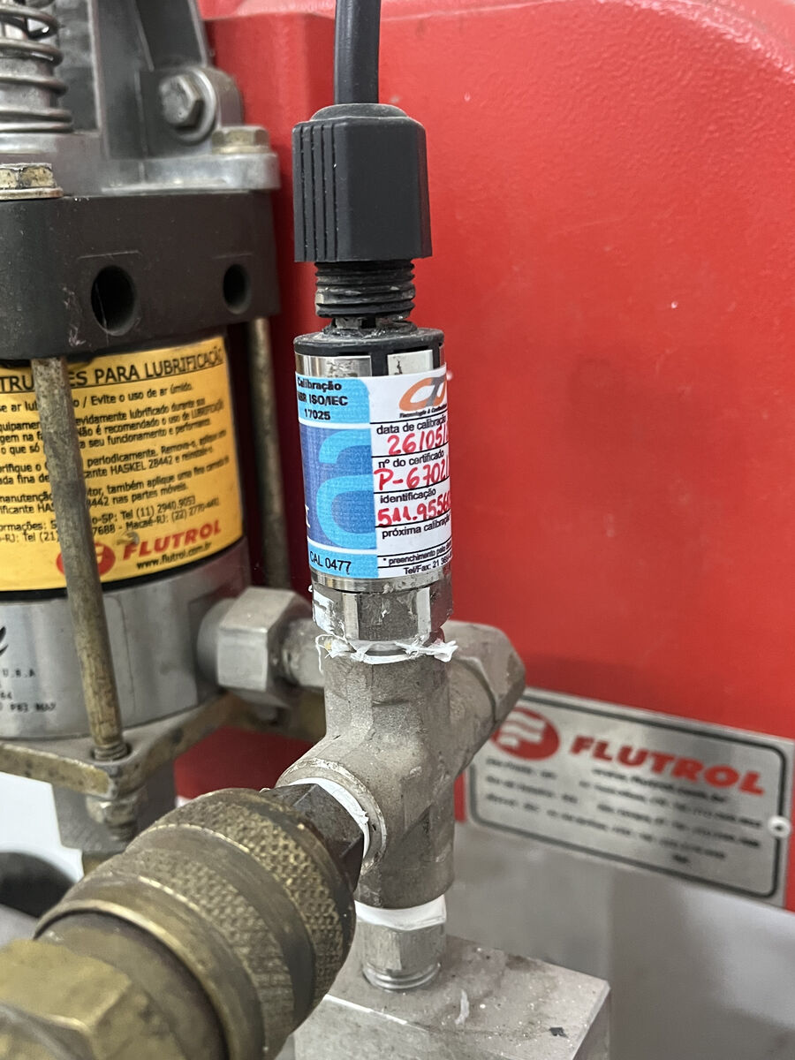
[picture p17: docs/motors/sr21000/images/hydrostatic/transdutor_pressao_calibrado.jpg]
<td><br>Transdutor de pressão calibrado para medições precisas</td>
</tr>
<tr>
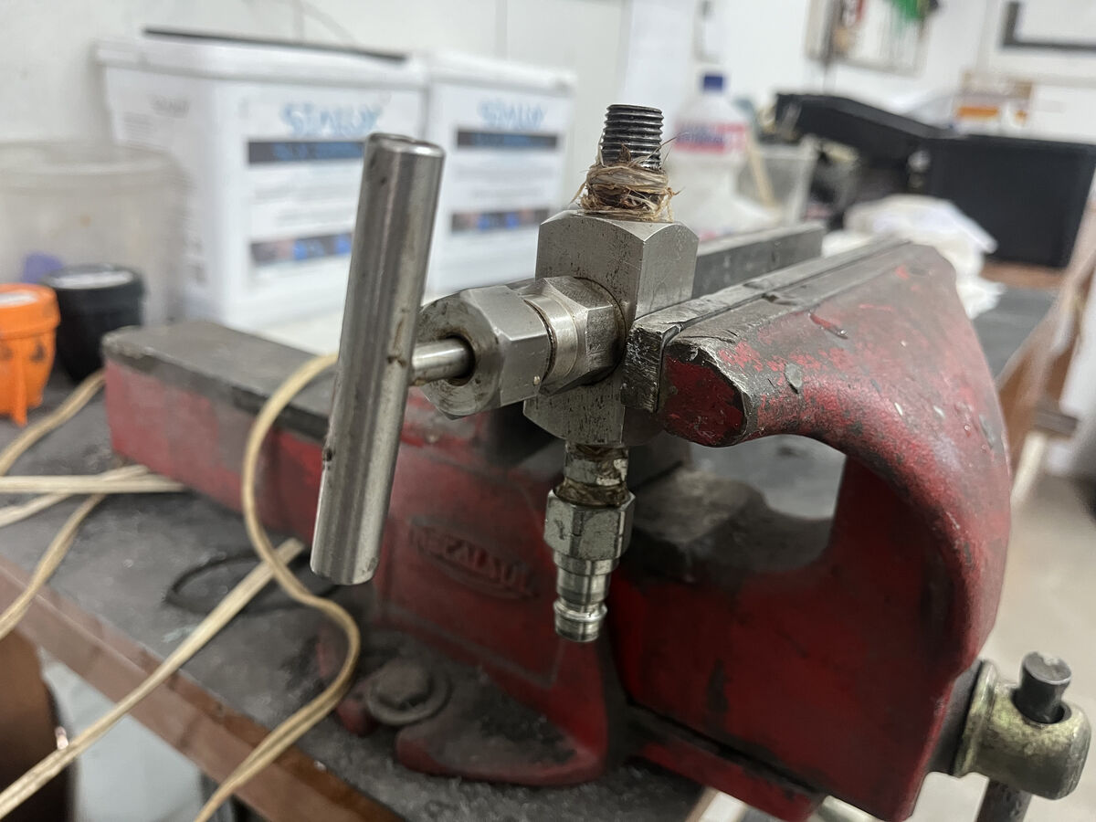
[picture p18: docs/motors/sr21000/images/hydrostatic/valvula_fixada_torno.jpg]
<td><br>Válvula fixada no torno para preparação</td>
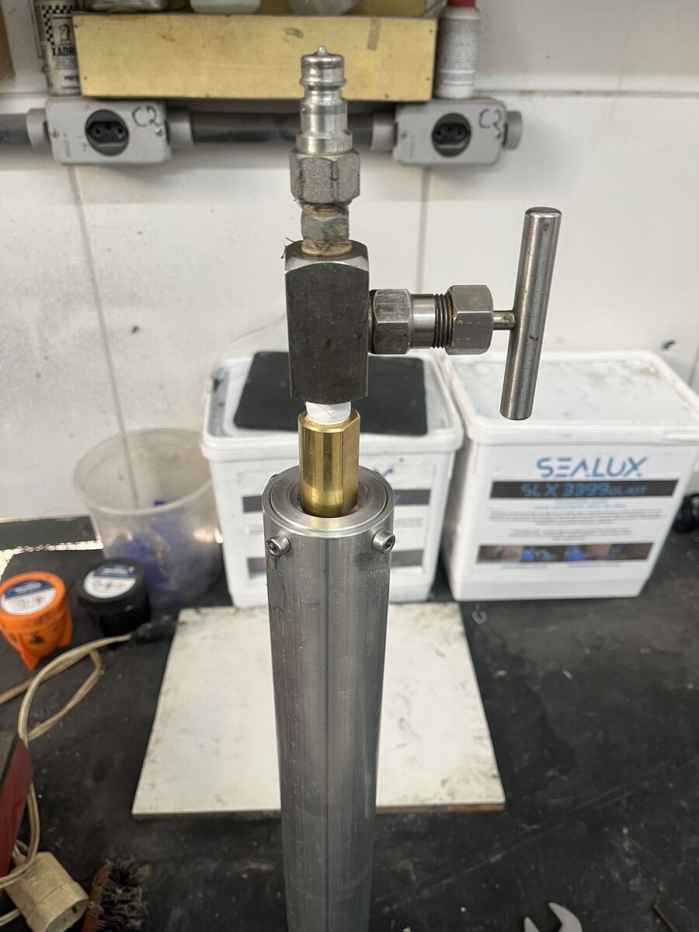
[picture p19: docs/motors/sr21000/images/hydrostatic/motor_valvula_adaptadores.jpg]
<td><br>Motor conectado à válvula e adaptadores</td>
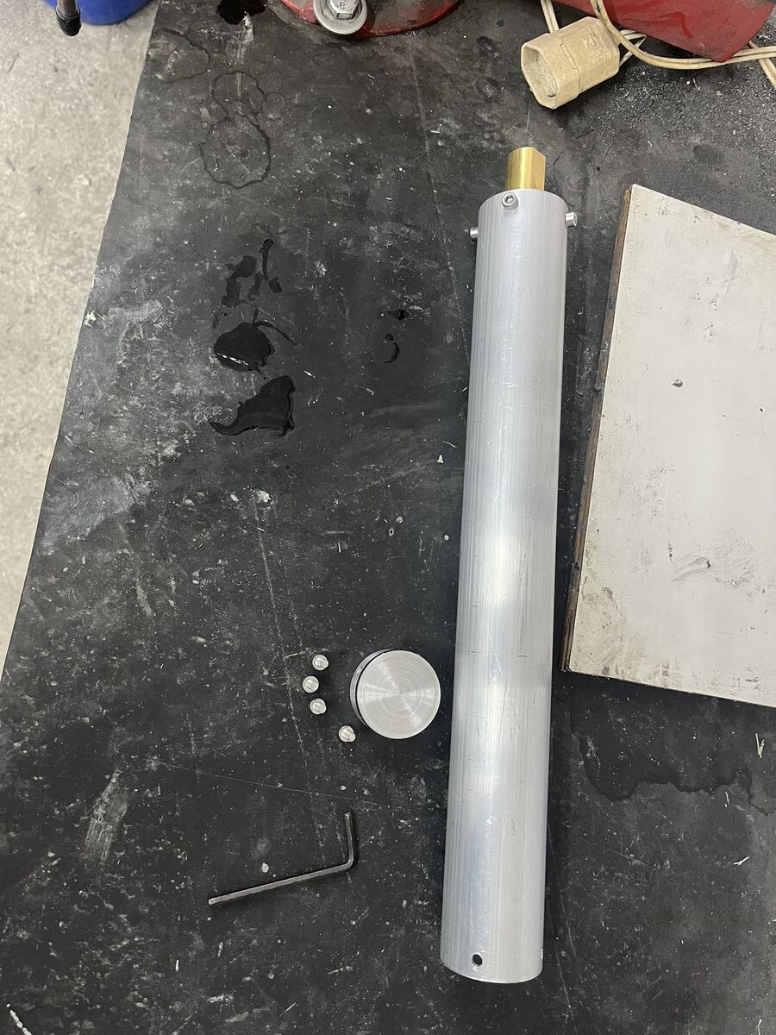
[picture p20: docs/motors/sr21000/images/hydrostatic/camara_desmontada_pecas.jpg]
<td><br>Câmara desmontada — todas as peças inspecionadas</td>
</tr>
<tr>
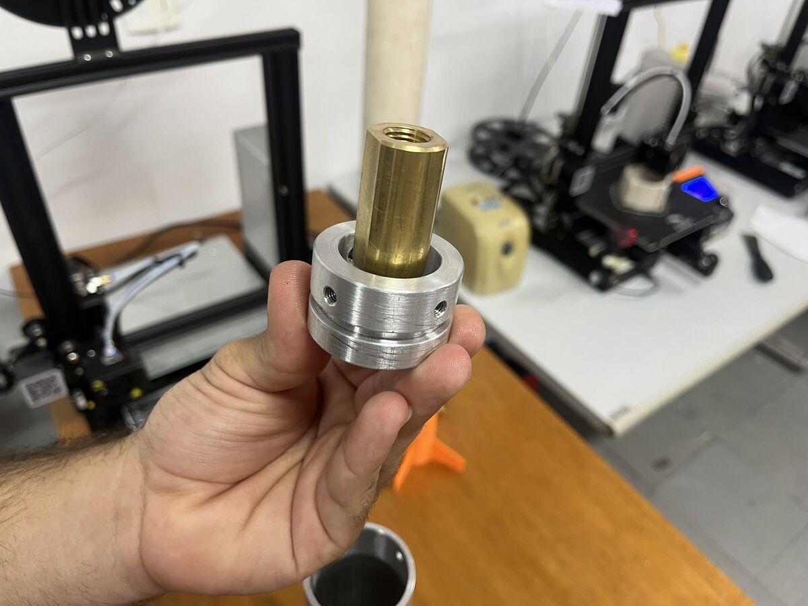
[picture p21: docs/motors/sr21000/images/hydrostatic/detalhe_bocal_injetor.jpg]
<td><br>Detalhe do bocal injetor de água</td>
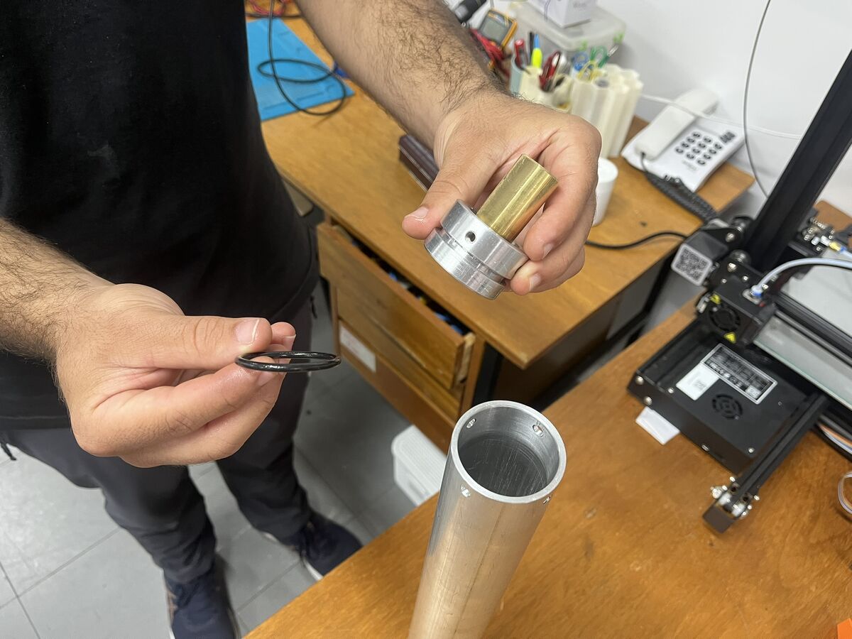
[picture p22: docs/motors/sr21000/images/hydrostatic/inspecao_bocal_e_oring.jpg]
<td><br>Inspeção do bocal e O'Ring antes do teste</td>
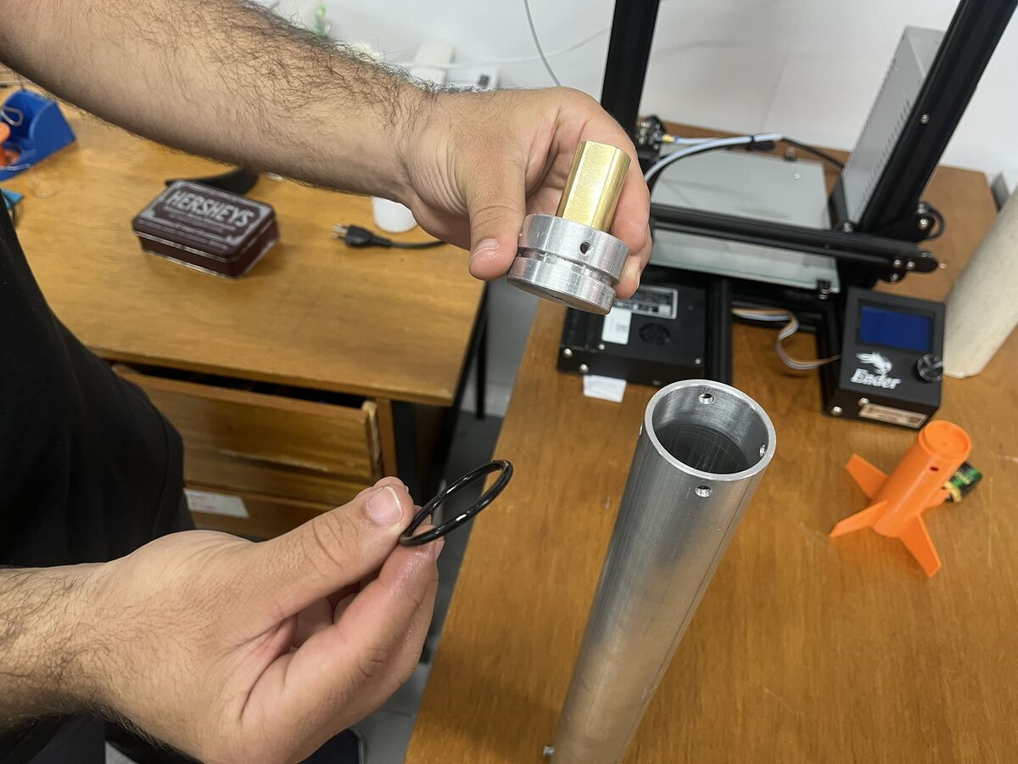
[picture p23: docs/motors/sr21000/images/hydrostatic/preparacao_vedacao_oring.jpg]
<td><br>Preparação da vedação com O'Ring</td>
</tr>
<tr>
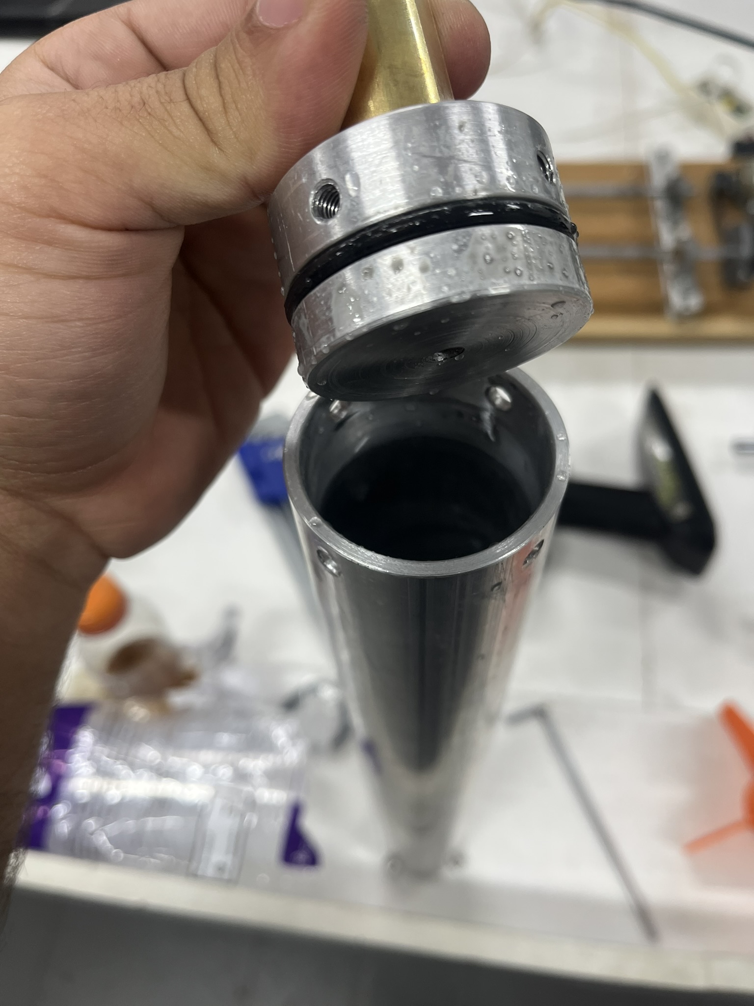
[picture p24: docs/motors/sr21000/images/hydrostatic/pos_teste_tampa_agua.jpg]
<td><br>Pós-teste — tampa removida mostrando água residual (confirma ausência de vazamentos)</td>
</tr>
</table>

**Dados brutos:** [`TESTE_HIDROSTATICO_SR21000_88bar.xlsx`](./TESTE_HIDROSTATICO_SR21000_88bar.xlsx) (1019 leituras, 1 amostra/segundo)

---

## Teste Estático

Com a estrutura validada pelo teste hidrostático, o próximo passo natural era o teste estático — a primeira queima real do motor. O teste estático é onde a teoria encontra a realidade: as simulações do OpenMotor dizem que o motor deve gerar 482 N de empuxo por 1.34 segundos, mas só o fogo vai confirmar.

> **⚠️ DADOS PENDENTES:** Os dados brutos do teste estático ainda não foram adicionados ao repositório. Consulte a [issue #18](https://github.com/Serra-Rocketry/motor/issues/18) para acompanhar o status.

---

## Voo

O SR21000 completou seu ciclo de vida: simulado, fabricado, testado hidrostaticamente, e最终mente levado ao voo. O motor foi integrado ao foguete e lançado — however, o voo não saiu como planejado. O foguete caiu balisticamente, sem a ativação do sistema de paraquedas.

Mas há um lado positivo: **o motor resistiu bem à queda**. Após a recuperação, a inspeção visual mostrou que o case, o nozzle e a bulkhead mantiveram sua integridade estrutural. Isso valida não apenas o projeto do motor, mas também a robustez da estrutura como um todo — afinal, uma queda balística impõe forças significativas sobre o conjunto.

> **⚠️ FOTOS PENDENTES:** As fotos do pós-voo ainda não foram adicionadas ao repositório. Consulte a [issue #22](https://github.com/Serra-Rocketry/motor/issues/22) para acompanhar o status.

---

## Arquivos do Projeto

### CAD (SolidWorks)

| Arquivo | Descrição |
|---|---|
| [`cad/MontagemSR21000.SLDASM`](./cad/MontagemSR21000.SLDASM) | Montagem principal |
| [`cad/Motor_SR21000_Humberto.SLDASM`](./cad/Motor_SR21000_Humberto.SLDASM) | Montagem alternativa |
| [`cad/Tubo.SLDPRT`](./cad/Tubo.SLDPRT) | Tubo do case |
| [`cad/Secao_Tubo.SLDPRT`](./cad/Secao_Tubo.SLDPRT) | Seção do tubo |
| [`cad/PCI4-8.SLDPRT`](./cad/PCI4-8.SLDPRT) | Componente PCI |
| [`cad/Inibidor_Papelao.SLDPRT`](./cad/Inibidor_Papelao.SLDPRT) | Inibidor de papelão |
| [`cad/Guia_alma_teste_de_prop.SLDPRT`](./cad/Guia_alma_teste_de_prop.SLDPRT) | Guia de alma (teste) |
| [`cad/moldeprop.SLDPRT`](./cad/moldeprop.SLDPRT) | Molde do propelente |
| [`cad/Nozzle.SLDPRT`](./cad/Nozzle.SLDPRT) | Nozzle |
| [`cad/Bulkhead.SLDPRT`](./cad/Bulkhead.SLDPRT) | Bulkhead v1 |
| [`cad/BulkheadV2.SLDPRT`](./cad/BulkheadV2.SLDPRT) | Bulkhead v2 |

### Desenhos Técnicos

| Arquivo | Descrição |
|---|---|
| [`drawings/Tubo_400mm.SLDDRW`](./drawings/Tubo_400mm.SLDDRW) | Desenho do tubo |
| [`drawings/Nozzle.SLDDRW`](./drawings/Nozzle.SLDDRW) | Desenho do nozzle |
| [`drawings/BulkheadV2_-_Copia.SLDDRW`](./drawings/BulkheadV2_-_Copia.SLDDRW) | Desenho da bulkhead |
| [`drawings/Bulkhead_Sensor_Pressao.pdf`](./drawings/Bulkhead_Sensor_Pressao.pdf) | Bulkhead com sensor de pressão |

### STL (Impressão 3D)

| Arquivo | Descrição |
|---|---|
| [`stl/Nozzle.STL`](./stl/Nozzle.STL) | Nozzle para impressão |
| [`stl/MoldeInibidor.STL`](./stl/MoldeInibidor.STL) | Molde do inibidor |

### Simulações OpenMotor

| Arquivo | Descrição |
|---|---|
| [`openmotor/nozzle_sr21000.ric`](./openmotor/nozzle_sr21000.ric) | Configuração final (throat 9.92 mm) |
| [`openmotor/Ideia_Inicial_SR21000.ric`](./openmotor/Ideia_Inicial_SR21000.ric) | Configuração inicial (throat 8 mm) |
| [`openmotor/SR21000_KNSB_150mm.ric`](./openmotor/SR21000_KNSB_150mm.ric) | Simulação com KNSB (150 mm) |
| [`openmotor/SR21000_KNSB_275mm.ric`](./openmotor/SR21000_KNSB_275mm.ric) | Simulação com KNSB (275 mm) |

### Parasolid (Interoperabilidade)

| Arquivo | Descrição |
|---|---|
| [`parasolid/Nozzle_14mmThroat.x_t`](./parasolid/Nozzle_14mmThroat.x_t) | Nozzle (formato universal) |
| [`parasolid/Motor_SR21000_Humberto.x_t`](./parasolid/Motor_SR21000_Humberto.x_t) | Montagem alternativa |
| [`parasolid/Montagem_Motor_SR21000.x_t`](./parasolid/Montagem_Motor_SR21000.x_t) | Montagem principal |

---

## Dados Faltando

Apesar do motor ter sido concluído e voado, ainda existem lacunas documentais que precisam ser preenchidas:

| # | Issue | Descrição |
|---|---|---|
| 1 | [#16](https://github.com/Serra-Rocketry/motor/issues/16) | Completar análises técnicas (tubo e pinos) |
| 2 | [#17](https://github.com/Serra-Rocketry/motor/issues/17) | Documentar teste hidrostático em detalhes |
| 3 | [#18](https://github.com/Serra-Rocketry/motor/issues/18) | Adicionar dados de teste estático |
| 4 | [#19](https://github.com/Serra-Rocketry/motor/issues/19) | Documentar inibidor de papelão |
| 5 | [#20](https://github.com/Serra-Rocketry/motor/issues/20) | Definir comprimento do tubo (400mm vs 500mm) |
| 6 | [#21](https://github.com/Serra-Rocketry/motor/issues/21) | Exportar dados numéricos das simulações OpenMotor |
| 7 | [#22](https://github.com/Serra-Rocketry/motor/issues/22) | Adicionar fotos pós-voo |

---

*Documento atualizado em 2026. Última revisão: motor concluído — teste hidrostático, teste estático e voo realizados.*

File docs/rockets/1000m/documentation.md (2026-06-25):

Materiais do foguete:

Tampa: Aluminio 3 pol
Tubo 3Pol x 1/8: Aluminio 6063-T5
Nozzle: Inox 3 pol (Liga a definir)
Parafuso: inox M5 ( Espessura a definir a partir da simulação)
Oring: Viton
Alma : Teflon e Nylon

Oring

Dimensões:

Simulações:

Open Motor:
Utilizamos o software OpenMotor para prever o comportamento da pressão nos componentes do motor e o empuxo gerado.

Meteor:

## 2. Validação dos Elementos de Fixação (Parafusos M6)
Conversão de carga
A pressão interna de  usada como limite de segurança superior em cálculos é convertida para o  :

Área da Tampa ()

Força Total de Expulsão ()
Como a tampa tem uma área de aproximadamente , a pressão interna será:

Carga Cortante por Parafuso ()

Não usamos apenas a tensão média (), mas sim a Equação de Jourawski. Para o cálculo da tensão máxima via Equação de Jourawski, utiliza-se o raio efetivo () derivado da área resistente normativa do parafuso M6 ().
Raio Efetivo (): derivado da área resistente

Primeiro Momento de Área (): para uma seção semicircular

Momento de Inércia (): para a seção circular do parafuso

Largura da Seção na Linha Neutra (): diâmetro efetivo na linha neutra

Tensão de Cisalhamento Máxima (Equação de Jourawski)
Conforme desenvolvido anteriormente, a tensão máxima ocorre na linha neutra da seção transversal do parafuso explícita pela fórmula:

Isso é feito porque o cisalhamento em parafusos circulares não é uniforme; ele atinge o máximo na linha neutra. Com uma carga cortante de  por parafuso, a tensão máxima de  nos diz exatamente o estresse no ponto mais crítico da seção transversal do M6.

### Propriedades Mecânicas do Material dos Parafusos
Os elementos de fixação especificados para o projeto possuem as seguintes propriedades nominais de resistência, baseadas na padronização para fixadores métricos de alta resistência da classe 12.9:
Tensão Limite de Resistência à Tração:
Tensão de Escoamento à Tração:
### Tensão de Escoamento ao Cisalhamento () pelo Critério de Tresca
Para a determinação da capacidade de carga do parafuso sob condições de corte puro na linha neutra, adota-se o Critério de Tresca (também conhecido como Teoria da Tensão Cisalhante Máxima).
De acordo com este critério, o escoamento de um material dúctil inicia-se quando a tensão cisalhante máxima em qualquer ponto atinge a metade da tensão de escoamento obtida no ensaio de tração uniaxial simples. Matematicamente, a relação é expressa por:

Substituindo o valor de escoamento à tração do aço liga 12.9 ():

Como os valores de tensão atuante do sistema  já incorporam um fator de segurança de 2,5, a escolha de um limite de escoamento mais conservador pelo critério de Tresca (540 MPa) consolida uma abordagem de projeto robusta e de alta confiabilidade mecânica, garantindo que o componente opere significativamente abaixo de sua capacidade real de escoamento em regime puramente elástico.
## 3. Análise de Esmagamento do Tubo (Bearing Stress)
A análise de esmagamento avalia a compressão na parede do furo.
Tensão de Esmagamento Atuante ()
A força de cada parafuso sendo  é distribuída na área projetada do furo :

O Fator de Esmagamento ()
Diferente da tração simples, um material em torno de um furo possui restrição lateral, o que gera um estado de tensão triaxial que endurece o material localmente. Conforme normas aeroespaciais (MMPDS) e mecânicas (Eurocode), para ligas de alumínio, o limite de esmagamento é majorado pelo fator 1,6:

Limite de Esmagamento Real () do alumínio 6063-T5:

A , a tensão de esmagamento atingiria aproximadamente   em parafuso. Como este valor ainda é inferior ao limite real de esmagamento (), o metal permanece no regime elástico, evitando a ovalização do furo.

Fazer com 8 parafusos M6 Aço liga 12.9 , fator de esmagamento 1,6

Simulação De Pressão Tubo:

Pressão da Simulação =  (F.S 2,5)*519,31 Psi = 1298,275 Psi

Simulação Parafusos:

A área da tampa é 0,00361567M^2 , logo a Força que a pressão de 519,31 Psi com Fator de Segurança 2,5 realiza é igual a 0,00361567M^2 * 8951291,0246(Pa) = 32.364,91 N

Logo a força que cada parafuso tem que resistir é 32364,91N /Número de Parafusos

Para uma análise inicial foram selecionados 4 parafusos M5 de Aço Inox, logo a força sobre cada parafuso é de 32364,91/4 = 8091,23 N

Resultado da simulação:

A partir da simulação , verificou-se que os 4 parafusos M5 de Aço Inox x 20mm resistiram ao esforço de cisalhamento de 8091,23 N.

Simular efeito da pressão no acoplamento parafuso tubo

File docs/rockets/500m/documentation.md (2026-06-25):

# Relatório Técnico de Propulsão: Dimensionamento e Testes Computacionais do Motor Sólido (Classe 500m)

## 1. Simulação de propelente (OpenMotor)
Utilizamos o software OpenMotor para prever o comportamento da pressão nos componentes do motor e o empuxo gerado.

Imagem 1 - Simulação de comportamento dos grãos.
Diâmetro Interno Câmara De Combustão - 40 mm
Comprimento Total Propelente - 250 mm
Número de Segmentos - 2
Diâmetro da Alma - 15 mm
Máxima Pressão De Operação - 350 Psi
Tempo de Queima - 1,59 s
Impulso Total - 559,71 Ns
Empuxo Máximo - ~ 550N
Empuxo Médio - ~ 380 N
Massa Propelente - 0,47 Kg
2. Materiais

Tubo (3” x ⅛”): Alumínio 6063-T5;
Tampa (3 Pol): Alumínio 6061;
Nozzle (3 Pol): Aço Inox AISI 304;
Parafuso (M5): Aço Inox AISI 304;
O’ring: Viton;
Alma: a definir.

## 3. Estudo de Pressão Radial e Resistência Mecânica do Tubo

A Pressão máxima de operação do motor é de 350 PSi , Para esse projeto utilizaremos um fator de segurança de 2.5 , sendo assim , todas os cálculos de esforços e simulações serão feitas considerando a pressão máxima com o fator de segurança aplicado, Sendo 875 PSi a pressão de simulação.

Imagem 2 - Simulação de pressão em tubo
A Partir da simulação de esforços pela pressão interna no tubo, temos como resultado todos os esforços dentro do limite elástico do material.

## 4. Validação dos Elementos de Fixação (Parafusos M5)
Conversão de carga
A pressão interna de  usada como limite de segurança superior em cálculos é convertida para o  :

Área da Tampa ()

Força Total de Expulsão ()
Como a tampa tem uma área de aproximadamente , a pressão interna será:

Carga Cortante por Parafuso ()

Não usamos apenas a tensão média (), mas sim a Equação de Jourawski. Para o cálculo da tensão máxima via Equação de Jourawski, utiliza-se o raio efetivo () derivado da área resistente normativa do parafuso M5 ().
Raio Efetivo (): derivado da área resistente

Primeiro Momento de Área (): para uma seção semicircular

Momento de Inércia (): para a seção circular do parafuso

Largura da Seção na Linha Neutra (): diâmetro efetivo na linha neutra

Tensão de Cisalhamento Máxima (Equação de Jourawski)
Conforme desenvolvido anteriormente, a tensão máxima ocorre na linha neutra da seção transversal do parafuso explícita pela fórmula:

Isso é feito porque o cisalhamento em parafusos circulares não é uniforme; ele atinge o máximo na linha neutra. Com uma carga cortante de  por parafuso, a tensão máxima de  nos diz exatamente o estresse no ponto mais crítico da seção transversal do M5.
Propriedades Mecânicas do Material dos Parafusos
Os elementos de fixação especificados para o projeto possuem as seguintes propriedades nominais de resistência, baseadas na padronização para fixadores métricos de alta resistência da classe A2-70:
Tensão Limite de Resistência à Tração:
Tensão de Escoamento à Tração:
### Tensão de Escoamento ao Cisalhamento () pelo Critério de Tresca
Para a determinação da capacidade de carga do parafuso sob condições de corte puro na linha neutra, adota-se o Critério de Tresca (também conhecido como Teoria da Tensão Cisalhante Máxima).
De acordo com este critério, o escoamento de um material dúctil inicia-se quando a tensão cisalhante máxima em qualquer ponto atinge a metade da tensão de escoamento obtida no ensaio de tração uniaxial simples. Matematicamente, a relação é expressa por:

Substituindo o valor de escoamento à tração do aço inox A2-70 ():

Como os valores de tensão atuante do sistema  já incorporam um fator de segurança de 2,5, a escolha de um limite de escoamento mais conservador pelo critério de Tresca (225 MPa) consolida uma abordagem de projeto robusta.
Embora a tensão atuante majorada esteja próxima do limite de Tresca, isso garante que, mesmo no pior cenário estatístico e com as cargas de segurança aplicadas, o componente ainda se manterá dentro do regime elástico de forma confiável.

## 5. Análise de Esmagamento do Tubo (Bearing Stress)
A análise de esmagamento avalia a compressão na parede do furo.
Tensão de Esmagamento Atuante ()
A força de cada parafuso sendo  é distribuída na área projetada do furo :

O Fator de Esmagamento ()
Diferente da tração simples, um material em torno de um furo possui restrição lateral, o que gera um estado de tensão triaxial que endurece o material localmente. Conforme normas aeroespaciais (MMPDS) e mecânicas (Eurocode), para ligas de alumínio, o limite de esmagamento é majorado pelo fator 1,5:
Limite de Esmagamento Real ():
A , a tensão de esmagamento atingiria aproximadamente . Como este valor ainda é inferior ao limite real de esmagamento (), o metal permanece no regime elástico, evitando a ovalização do furo.

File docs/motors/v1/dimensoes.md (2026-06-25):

Diâmetro tampa motor 22mm
Diâmetro motor 19.5mm
comprimento 200.6mm

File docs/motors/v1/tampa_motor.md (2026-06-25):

13,50
17,70
R8,85mm
A A
Rosca M3
Rosca M3
R6,75mm

8
8
,
1

R1,31
SEÇÃO A-A
10,00
Cotas Em mm
13,00

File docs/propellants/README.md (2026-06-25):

# Propulsores (Propelentes)

Dados de testes de queima e caracterização de propelentes sólidos.

## Testes

### Teste de Queima — 09/06/2023

Teste de 14 formulações de propelente com variações de:
- Proporção KNO3/Açúcar (50/50, 65/35, 70/30)
- Substituição de Açúcar por Dextrose
- Adição de óxidos metálicos (CuFe2O4, CoFe2O4, NiFe2O4, ZnFe2O4)
- Adição de Clorato de Sódio

Documentação: [teste_queima_2023-06-09.md](./teste_queima_2023-06-09.md)

GIFs dos testes em [gifs/](./gifs/).

### Teste de Granulometria — Nitrato de Potássio

Avaliação de diferentes granulometrias de KNO3 para otimizar o desempenho do propelente.

Documentação: [granulometry_test_description.md](./granulometry_test_description.md)

## Dados

| Arquivo | Descrição |
|---|---|
| [dados_propelentes.xlsx](./dados_propelentes.xlsx) | Dados do teste de queima 09/06/2023 |
| [teste_reprodutibilidade.xlsx](./teste_reprodutibilidade.xlsx) | Teste de reprodutibilidade |
| [planilha_teste_estufa.xlsx](./planilha_teste_estufa.xlsx) | Dados do teste em estufa |

## Referências

- [KNSU Rocket Candy](https://www.nakka-rocketry.net/articles/sucrose_prop.html) — referência de propelentes KNSU/KND
- [OpenMotor](https://github.com/reilleya/openMotor) — software de simulação de motores

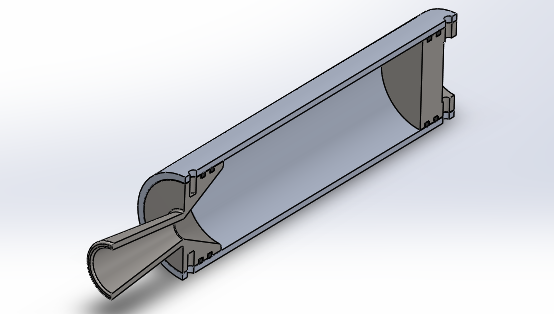
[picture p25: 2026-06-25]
docs/motors/sr21000/images/capturas/render_corte_sr21000.png

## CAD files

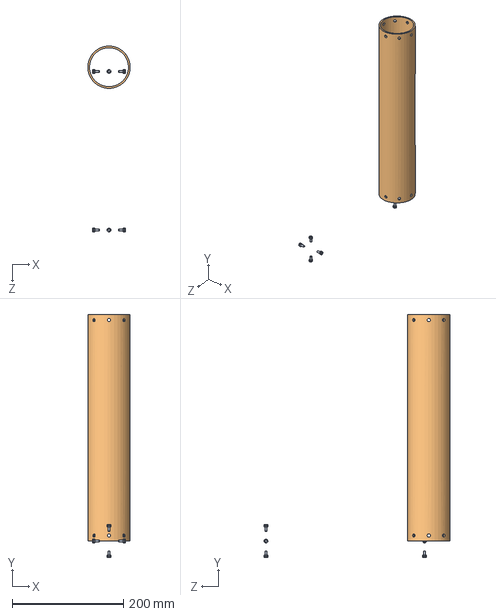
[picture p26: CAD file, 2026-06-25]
docs/rockets/500m/assembly/Mont1.SLDASM
76.2 x 436.5 x 334.1 mm
Tubo
PCI4-8 x 8

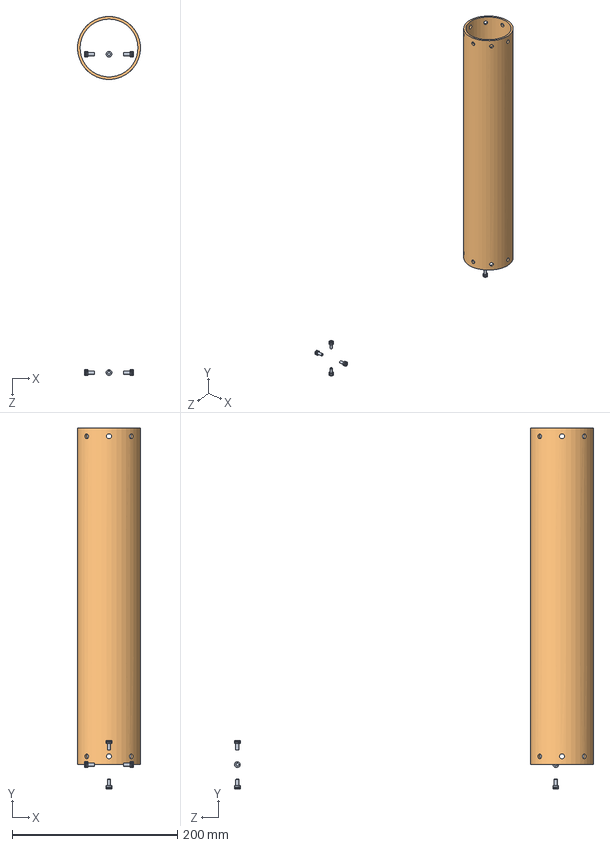
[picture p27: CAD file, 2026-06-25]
docs/motors/sr21000/cad/Motor_SR21000_Humberto.SLDASM
76.2 x 436.5 x 434.1 mm
Tubo
PCI4-8 x 8

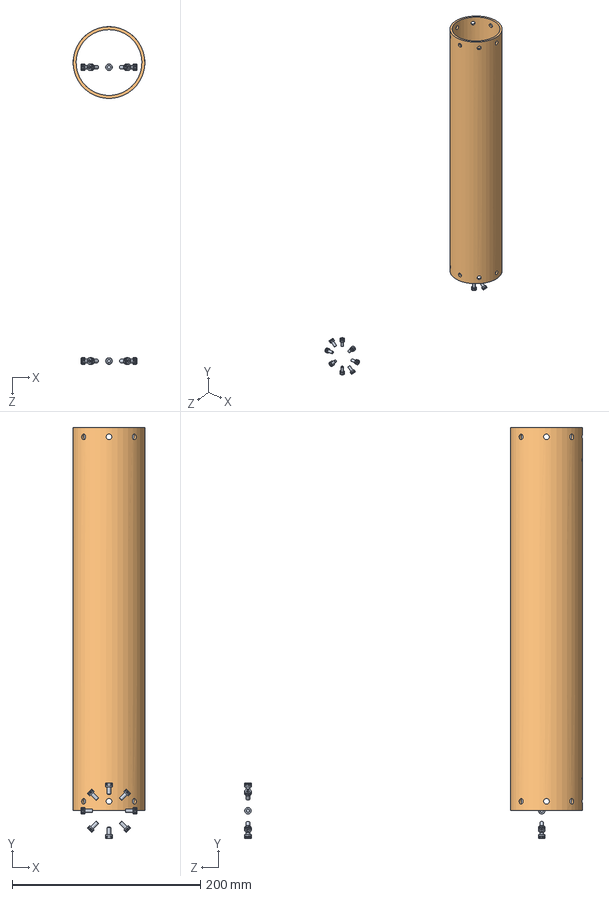
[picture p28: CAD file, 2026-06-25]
docs/motors/sr21000/cad/MontagemSR21000.SLDASM
76.2 x 436.5 x 358.6 mm
Tubo
PCI4-8 x 16

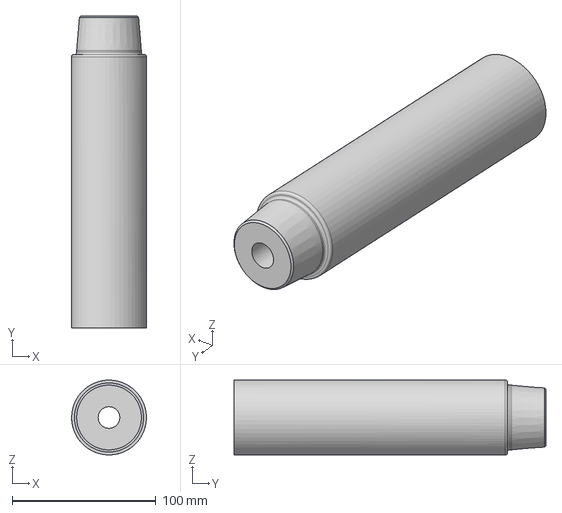
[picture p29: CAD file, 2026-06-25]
docs/molds/tubo.step
52.0 x 216.7 x 52.0 mm

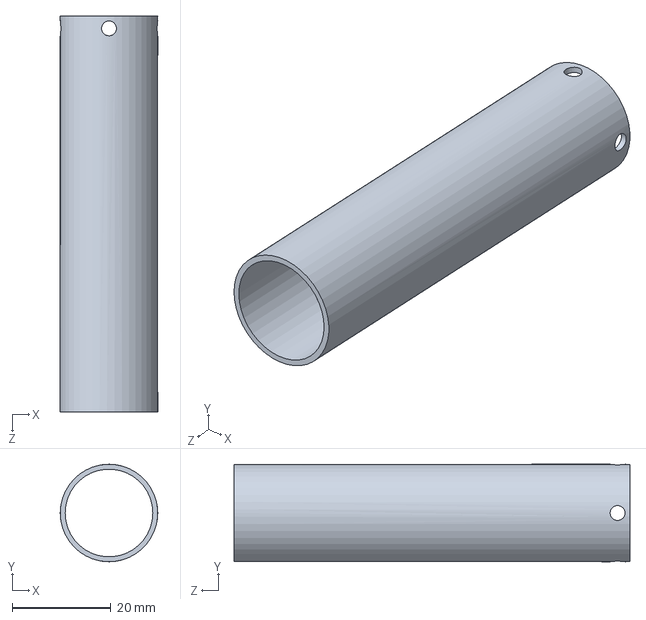
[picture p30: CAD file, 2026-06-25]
docs/motors/300m/cad/motor.SLDPRT
19.7 x 19.7 x 80.0 mm

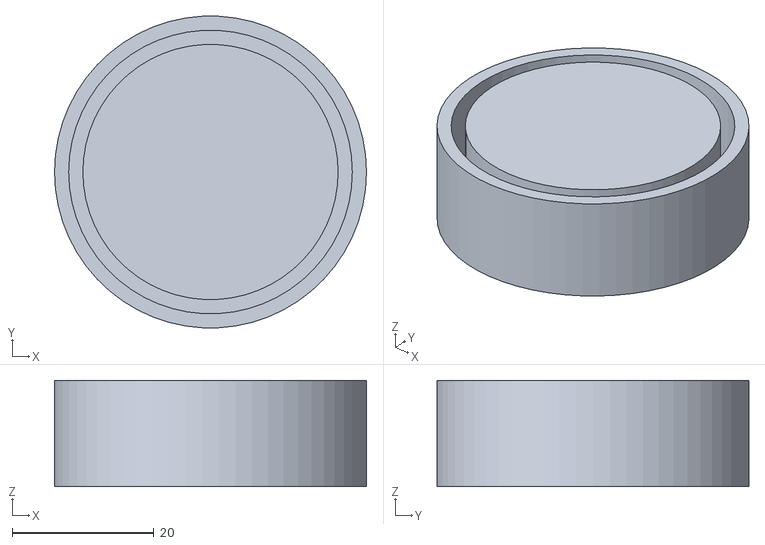
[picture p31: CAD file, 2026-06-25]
docs/motors/cardboard/cap/tampa_motor_v2_-_Part_1.stl
44.0 x 43.9 x 15.0

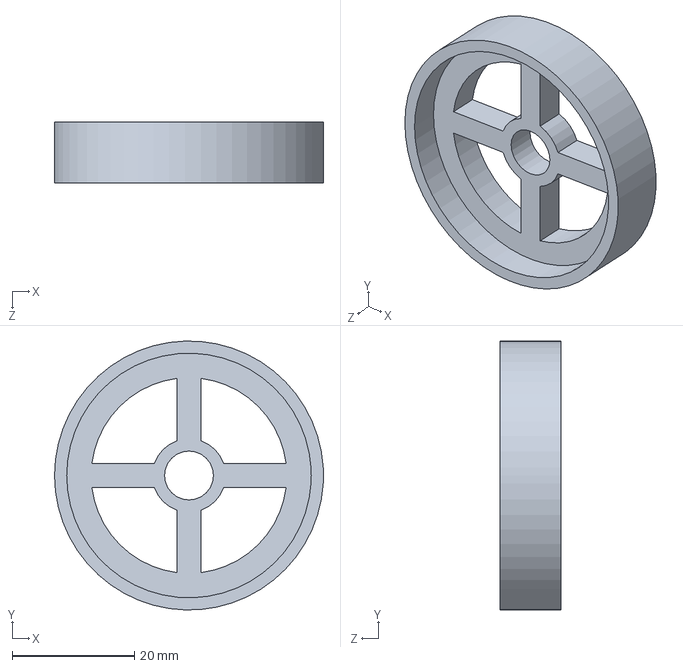
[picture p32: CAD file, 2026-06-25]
docs/motors/cardboard/mold/TampaBracadeira2.SLDPRT
44.0 x 44.0 x 10.0 mm

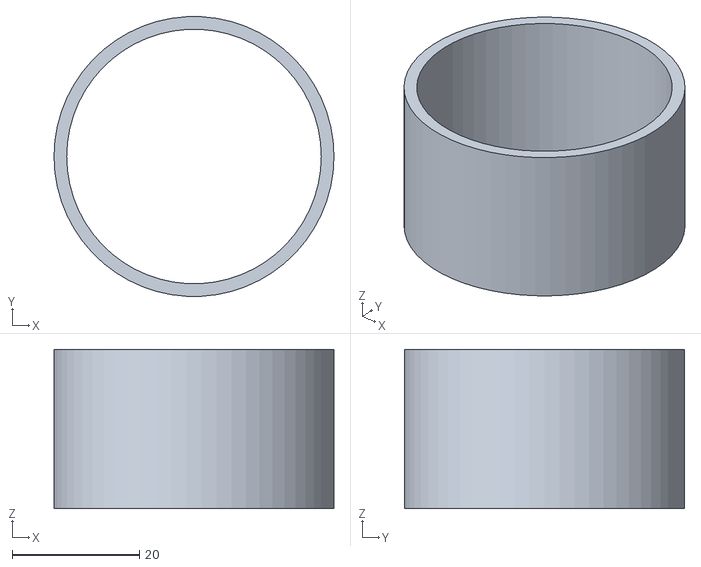
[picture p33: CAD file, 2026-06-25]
docs/motors/cardboard/ring/tampa_motor_v2_Copy_1_-_Part_1.stl
44.0 x 43.9 x 25.0

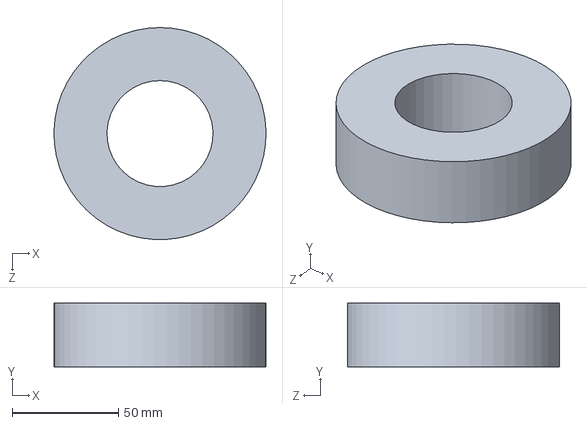
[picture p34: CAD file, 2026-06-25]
docs/motors/sr21000/cad/moldeprop-Ressalto-extrusao3.SLDPRT
100.0 x 30.0 x 99.9 mm

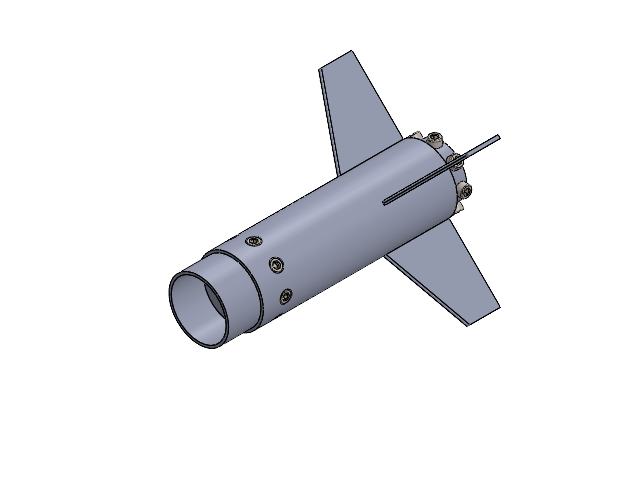
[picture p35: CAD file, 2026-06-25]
docs/motors/sr1500/cad/Montagem_motor_pica.SLDASM
Aleta Motor Pica
Tampa_motor
Restrição_motor
tubo motor
M4x6 x 17

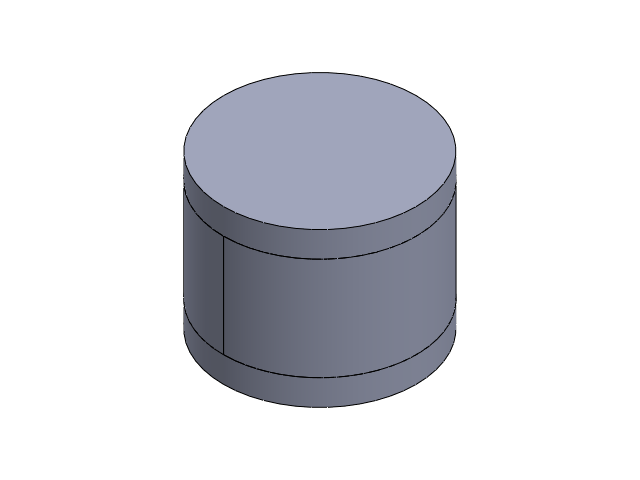
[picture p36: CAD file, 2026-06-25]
docs/nozzle/assembly/Montagem_Nozzle.SLDASM
Base Molde
Meio 1 Molde
Meio 2 Molde
Topo Molde

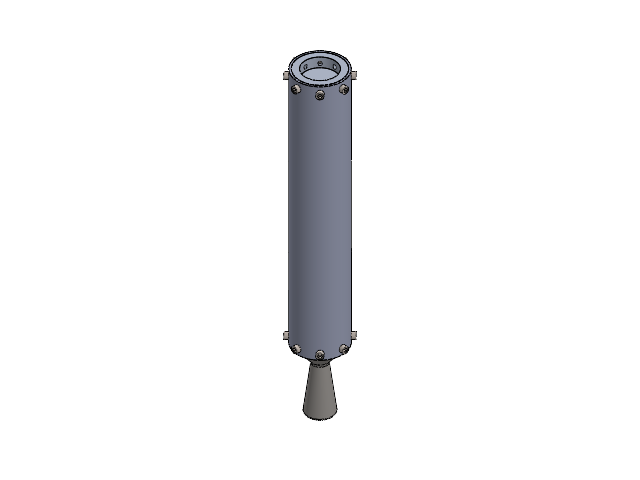
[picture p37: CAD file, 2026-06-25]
docs/rockets/1000m/assembly/Montagem_Motor_1KM.SLDASM
tubo
nozzle
tampa
Parafuso x 16

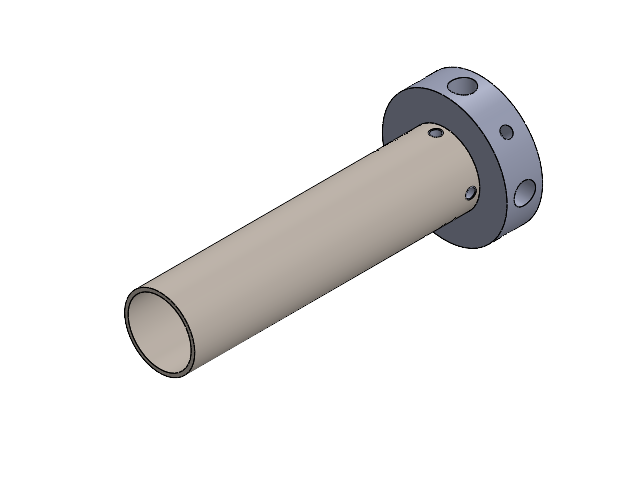
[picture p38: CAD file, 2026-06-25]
docs/motors/300m/cad/Montagem_Guia_Motor_Fuselagem.SLDASM
Acoplamento motor fuselagem
Tampa Motor
motor

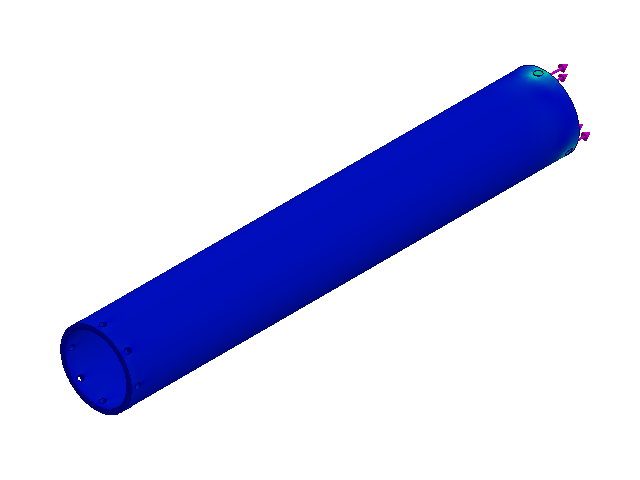
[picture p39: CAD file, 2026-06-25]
docs/motors/sr21000/cad/Montsimtubo.SLDASM
Tubo
Pino_ParafusoSim x 3

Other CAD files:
docs/rockets/1000m/assembly/Mont1.SLDASM
docs/motors/sr21000/cad/Montagem.SLDASM
docs/motors/sr21000/cad/MontagemPino.SLDASM
docs/motors/sr21000/cad/Montagem_teste_hidrostatico.SLDASM
docs/archive/nozzle-cemento/cad/Base_Molde.SLDPRT
docs/archive/nozzle-cemento/cad/Meio_1_Molde.SLDPRT
docs/archive/nozzle-cemento/cad/Meio_2_Molde.SLDPRT
docs/archive/nozzle-cemento/cad/Topo_Molde.SLDPRT
docs/molds/base.step
docs/molds/funil.step
docs/motors/300m/cad/Acoplamento_motor_fuselagem.SLDPRT
docs/motors/300m/cad/GUIAALMA.SLDPRT
docs/motors/300m/cad/Tampa_Motor.SLDPRT
docs/motors/300m/stl/Acoplamento_motor_fuselagem.STL
docs/motors/300m/stl/GUIAALMA.STL
docs/motors/cardboard/mold/Bracadeira.SLDPRT
docs/motors/cardboard/mold/Bracadeira.STL
docs/motors/cardboard/mold/TampaBracadeira.SLDPRT
docs/motors/cardboard/mold/TampaBracadeira.STL
docs/motors/cardboard/mold/TampaBracadeira2.STL
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

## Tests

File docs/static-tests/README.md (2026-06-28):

# Testes Estáticos

Dados brutos e gráficos de testes estáticos de motores de foguete.

## Testes Disponíveis

| Motor | Dados | Gráfico | SciLab |
|---|---|---|---|
| [Motor Gabriel](./motor-gabriel/) | [data.txt](./motor-gabriel/data.txt) | — | — |
| [Motor Caramelo](./motor-caramelo/) | [data.txt](./motor-caramelo/data.txt) | [empuxo_pressao.jpg](./motor-caramelo/empuxo_pressao.jpg) | [motor_caramelo.sciprj](./scilab/motor_caramelo.sciprj) |
| Motor I (69-31 Grãos torrados) | — | [empuxo_pressao.jpg](./motor-i/empuxo_pressao.jpg) | [motor_i.sciprj](./scilab/motor_i.sciprj) |

## Formato dos Dados

Os dados brutos do SD card seguem o formato:

```
HH:MM:SS ; empuxo(kN) ; tempo(ms)
```

Exemplo (Motor Gabriel):
```
12:17:22 ; 0.007 ; 114500
12:17:22 ; 0.007 ; 114600
12:17:23 ; 0.006 ; 114700
```

## Análise

Os projetos SciLab (`.sciprj`) em [scilab/](./scilab/) podem ser abertos com [Scilab](https://www.scilab.org/) para análise e geração de gráficos.

## Sistema de Aquisição

O sistema de aquisição de dados (thrust stand) fica no repositório [Serra-Rocketry/thrust-stand](https://github.com/Serra-Rocketry/thrust-stand). Este diretório contém apenas os dados coletados.

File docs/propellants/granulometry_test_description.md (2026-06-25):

Teste De Granulometria
Nitrato de Potássio
Serra Rocketry

Objetivos:

Avaliar o desempenho de diferentes granulometrias de nitrato de potássio e a partir dos dados obtidos, documentar os parâmetros obtidos e determinar o tamanho de grão a ser utilizado nos propelentes de acordo com a eficiência e dificuldade de produção ( Maior facilidade X Maior eficiência).

Materiais e Métodos:

- Materiais:

-  10 Tubos de alumínio 80 mm comprimento x 17,5 mm diâmetro interno
-  Papel Cartão
-  Nitrato de Potássio (Diferentes Granulometrias)
-  Açúcar Refinado (Triturado e Peneirado)
-  Broca 6mm (Para furar a alma)
-  Guia para centralizar o furo
-  Triturador
-  Prensa hidraulica
-  Peneira de cozinha
-  Tarugo para prensar o propelente
-  Parafusadeira

- Metodologia:

- Serão desenvolvidos 10 motores semelhantes em dimensões e massa , seguindo o padrão 10 mm de tampa , 50 mm de propelente e 10 mm de restrição , sobrando 10 mm para auxiliar durante a produção .

- O material utilizado para tampa e restrição será argila compactada.

- para compactar a tampa o propelente e a restrição será utilizado uma prensa hidráulica , será utilizado a força de 1 tonelada durante a prensagem.

- Os motores serão :

2 - KNSU (65% KNO3 ; 35% Açúcar) - Granulometria
250mm >x>150mm;
2 - KNSU (65% KNO3 ; 35% Açúcar) - Granulometria 75µm>x>45µm;
2 - KNSU (65% KNO3 ; 35% Açúcar) - Granulometria 75µm<x<150 µm;
2 - KNSU (65% KNO3 ; 35% Açúcar) - Granulometria x>250µm
2 - KNSU (65% KNO3 ; 35% Açúcar) - Peneira comum.

- Passo a Passo para fabricação:

1 ª - Separar os materiais e as ferramentas que vão ser utilizados ;
2 ª - Triturar o açúcar por 2 minutos , parando para mexer de 30 em 30 segundos;
3 ª - Peneirar o açúcar com a peneira comum;
4 ª - Identificar os motores de acordo com a granulometria do nitrato;
5 ª - Cortar e inserir o papel cartão nos motores ;
6 ª - Iniciar a prensagem dos motores (conforme a figura 1);
7 ª - Furar a alma dos motores utilizando o guia ;
8 ª - Deixar os motores na estufa por 30 minutos;
9 ª - Retirar os motores da estufa e isolar com plástico cada motor para evitar umidade.

- Após a prensagem o motor deverá ficar assim:
Figura 1 - Motor após a prensagem

- Após o furo da alma o motor deverá ficar assim:
Figura 2 - Motor após o furo da alma

- Resultados:

Granulometria 250mm >x>150mm;

Motor 1:
Motor 2:

Granulometria 75mm >x>45mm;

Motor 3:
Motor 4:

Granulometria x>250mm;

Motor 5:
Motor 6:

Peneira Comum;

Motor 7:
Motor 8:

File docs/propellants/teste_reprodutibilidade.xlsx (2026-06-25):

Propelente KNSU Sem Óxido - 72h De Estufa a 50 degC
Amostra | Comprimento (mm) | Incert Do Comp (mm) | Tempo De Queima (s) | Incert Do Tempo De Queima (s) | Velocidade De Queima (mm/s) | Incert Da Velocidade De Queima (mm/s)
1 | 107.25 | 1 | 30 | 0.5 | 3.575 | 0.065
2 | 97.35 | - | 29 | - | 3.357 | -
3 | 98.15 | - | 29.6 | - | 3.316 | -
4 | 104.65 | - | 32 | - | 3.270 | -
5 | 102.75 | - | 31 | - | 3.315 | -
Propelente KNSU Sem Óxido - 72h De Estufa a 50 degC
Amostra | Comprimento (mm) | Incert Do Comp (mm) | Tempo De Queima (s) | Incert Do Tempo De Queima (s) | Velocidade De Queima (mm/s) | Incert Da Velocidade De Queima (mm/s)
1 | 99.2 | 1 | 29 | 0.5 | 3.421 | 0.065
2 | 103.4 | - | 33 | - | 3.133 | -
3 | 103.75 | - | 33.47 | - | 3.100 | -
4 | 86.1 | - | 24.8 | - | 3.472 | -
5 | 92.55 | - | 27.1 | - | 3.415 | -
Propelente KNSU Sem Óxido - 100h De Estufa a 60 degC
Amostra | Comprimento (mm) | Incert Do Comp (mm) | Tempo De Queima (s) | Incert Do Tempo De Queima (s) | Velocidade De Queima (mm/s) | Incert Da Velocidade De Queima (mm/s)
1 | 109.5 | 1 | 32 | 0.5 | 3.422 | 0.065
2 | 118.4 | - | 34.1 | - | 3.472 | -
3 | 110.5 | - | 33.1 | - | 3.338 | -
4 | 121 | - | 35.8 | - | 3.380 | -
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

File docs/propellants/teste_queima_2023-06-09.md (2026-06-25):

# Teste de Queima — 09/06/2023

Teste de queima de diferentes formulações de propelente sólido (KNSU/KND) com adição de óxidos metálicos como catalisadores.

**Data:** 09 de junho de 2023
**Procedimento:** Amostras de 10 cm, aferição do tempo de queima, verificação e pesagem dos resíduos.

## Formulações Testadas

### Propelente 1 — KNSU Padrão

**Composição:** 65% Nitrato de Potássio — 35% Açúcar ("Jeito Padrão")
**Massa:** 16,25g Nitrato + 8,75g Açúcar

Propelente 1 — KNSU Padrão

---

### Propelente 2 — KNSU "Jeito do Coroa"

**Composição:** 65% Nitrato de Potássio — 35% Açúcar ("Jeito do coroa")
**Massa:** 16,25g Nitrato + 8,75g Açúcar

> **TODO:** Verificar qual a diferença do "jeito do coroa" em relação ao padrão. Ver issue [#1](https://github.com/Serra-Rocketry/motor/issues/1).

Propelente 2 — KNSU Coroa

---

### Propelente 3 — KNSU 70/30

**Composição:** 70% Nitrato de Potássio — 30% Açúcar
**Massa:** 17,5g Nitrato + 7,5g Açúcar

Propelente 3 — KNSU 70/30

---

### Propelente 4 — 50/50

**Composição:** 50% Nitrato de Potássio — 50% Açúcar
**Massa:** 12,5g Nitrato + 12,5g Açúcar

Propelente 4 — 50/50

---

### Propelente 5 — KND (Dextrose)

**Composição:** 65% Nitrato de Potássio — 35% Dextrose
**Massa:** 16,25g Nitrato + 8,75g Dextrose

Propelente 5 — KND

**Parte 2:**

Propelente 5 — Dextrose Parte 2

---

### Propelente 6 — Dextrose + CuFe2O4

**Composição:** 65% Nitrato — 34,5% Dextrose — 0,5% Óxido de Ferro CuFe2O4
**Massa:** 16,25g Nitrato + 4,25g Dextrose + 0,125g CuFe2O4

> **Nota:** Sem vídeo de teste disponível.

---

### Propelente 7 — Açúcar + CuFe2O4

**Composição:** 65% Nitrato — 34,5% Açúcar — 0,5% Óxido de Ferro CuFe2O4
**Massa:** 16,25g Nitrato + 4,25g Açúcar + 0,125g CuFe2O4

Propelente 7 — CuFe2O4

---

### Propelente 8 — Açúcar + CoFe2O4

**Composição:** 65% Nitrato — 34,5% Açúcar — 0,5% Óxido de Ferro CoFe2O4
**Massa:** 16,25g Nitrato + 4,25g Açúcar + 0,125g CoFe2O4

Propelente 8 — CoFe2O4

---

### Propelente 9 — Açúcar + NiFe2O4

**Composição:** 65% Nitrato — 34,5% Açúcar — 0,5% Óxido de Ferro NiFe2O4
**Massa:** 16,25g Nitrato + 4,25g Açúcar + 0,125g NiFe2O4

Propelente 9 — NiFe2O4

---

### Propelente 10 — Açúcar + ZnFe2O4

**Composição:** 65% Nitrato — 34,5% Açúcar — 0,5% Óxido de Ferro ZnFe2O4
**Massa:** 16,25g Nitrato + 4,25g Açúcar + 0,125g ZnFe2O4

Propelente 10 — ZnFe2O4

---

### Propelente 11 — KNSU + Clorato de Sódio

**Composição:** 65% Nitrato — 30% Açúcar — 5% Clorato de Sódio
**Massa:** 32,5g Nitrato + 15g Açúcar + 2,5g Clorato De Sódio

> **Nota:** Sem vídeo de teste disponível.

---

### Propelente 12 — KND + Clorato de Sódio

**Composição:** 65% Nitrato — 30% Dextrose — 5% Clorato de Sódio
**Massa:** 32,5g Nitrato + 15g Dextrose + 2,5g Clorato De Sódio

> **Nota:** Sem vídeo de teste disponível.

---

### Propelente 13 — KNSU + Clorato + Óxido

**Composição:** 65% Nitrato — 30% Açúcar — 4% Clorato de Sódio — 1% Óxido de Ferro (qualquer)
**Massa:** 32,5g Nitrato + 15g Açúcar + 2g Clorato De Sódio + 0,5g Óxido de Ferro

> **Nota:** Sem vídeo de teste disponível.

---

### Propelente 14 — KNSU + CuFe2O4 (1%)

**Composição:** 65% Nitrato — 34% Açúcar — 1% CuFe2O4
**Massa:** 32,5g Nitrato + 17g Açúcar + 0,5g ZnFe2O4

> **Nota:** Sem vídeo de teste disponível. Caso consigam fazer com 0,5%, fazer mais com 1% para testarmos se mais óxido é pior ou melhor.

---

## Dados Complementares

- [Dados de propelentes (xlsx)](./dados_propelentes.xlsx)
- [Teste de reprodutibilidade (xlsx)](./teste_reprodutibilidade.xlsx)
- [Planilha teste estufa (xlsx)](./planilha_teste_estufa.xlsx)
- [Descrição do teste de granulometria](./granulometry_test_description.md)

## Observações

- Anotar tudo durante o processo de fabricação, conformação e armazenamento
- Preencher todas as linhas e colunas da planilha no Google Drive
- Os vídeos foram convertidos para GIF (320px, 8fps) a partir dos originais .MOV

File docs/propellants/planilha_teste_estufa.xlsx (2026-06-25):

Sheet: Pos-pros
 | 24 Horas de Estufa
 | Método 1 |  |  | Método 2 |  |  | Método 3 |  |  | Método 4
 | 1 | 2 | 3 | 1 | 2 | 3 | 1 | 2 | 3 | 1 | 2 | 3
Comprimento (cm) | 5.8000 | 6.2000 | 6.0000 | 7.0000 | 5.5000 | 4.5000 | 5.0000 | 4.5000 | 4.5000 | 2.5000 | 5.0000 | 3.5000
tempo de queima (s) | 35.0000 | 18.0000 | 24.0000 | 16.0000 | 29.0000 | 17.0000 | 45.0000 | 37.0000 | 41.0000 | 13.0000 | 23.0000 | 9.0000
Peso antes (g) | 5.7600 | 6.4700 | 5.7500 | 7.6100 | 6.2900 | 5.8800 | 7.5800 | 6.3300 | 5.1400 | 1.6500 | 4.7800 | 3.8400
Peso depois (g) | 5.7500 | 6.4600 | 5.7200 | 7.6000 | 6.2800 | 5.8800 | 7.5400 | 6.3000 | 5.1000 | 1.6500 | 4.7700 | 3.8200
Velocidade de queima (cm/s) | 0.1657 | 0.3444 | 0.2500 | 0.4375 | 0.1897 | 0.2647 | 0.1111 | 0.1216 | 0.1098 | 0.1923 | 0.2174 | 0.3889
Taxa de Secagem (%) | 0.1736 | 0.1546 | 0.5217 | 0.1314 | 0.1590 | 0.0000 | 0.5277 | 0.4739 | 0.7782 | 0.0000 | 0.2092 | 0.5208
Velocidade Média (cm/s) | 0.2534 |  |  | 0.2973 |  |  | 0.1142 |  |  | 0.2662
Taxa de Secagem Média (%) | 0.2833 |  |  | 0.0968 |  |  | 0.5933 |  |  | 0.2433
 | 48 Horas de Estufa
 | Método 1 |  |  | Método 2 |  |  | Método 3 |  |  | Método 4
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

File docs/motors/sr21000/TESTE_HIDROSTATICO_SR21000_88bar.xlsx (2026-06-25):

DATE | Tempo | Press 4 | Pressão
26/08/2025 | 12:04:53 | -0.20 | -2.90076
26/08/2025 | 12:04:54 | -0.20 | -2.90076
26/08/2025 | 12:04:55 | -0.20 | -2.90076
26/08/2025 | 12:04:56 | -0.20 | -2.90076
26/08/2025 | 12:04:57 | -0.30 | -4.35114
26/08/2025 | 12:04:58 | -0.30 | -4.35114
26/08/2025 | 12:04:59 | -0.30 | -4.35114
26/08/2025 | 12:05:00 | -0.30 | -4.35114
26/08/2025 | 12:05:01 | -0.30 | -4.35114
26/08/2025 | 12:05:02 | -0.30 | -4.35114
26/08/2025 | 12:05:03 | -0.30 | -4.35114
26/08/2025 | 12:05:04 | -0.40 | -5.80152
26/08/2025 | 12:05:05 | -0.30 | -4.35114
26/08/2025 | 12:05:06 | -0.30 | -4.35114
26/08/2025 | 12:05:07 | -0.30 | -4.35114
26/08/2025 | 12:05:08 | -0.30 | -4.35114
26/08/2025 | 12:05:09 | -0.40 | -5.80152
26/08/2025 | 12:05:10 | -0.40 | -5.80152
26/08/2025 | 12:05:11 | -0.40 | -5.80152
26/08/2025 | 12:05:12 | -0.40 | -5.80152
26/08/2025 | 12:05:13 | -0.40 | -5.80152
26/08/2025 | 12:05:14 | -0.40 | -5.80152
26/08/2025 | 12:05:15 | -0.40 | -5.80152
26/08/2025 | 12:05:16 | -0.40 | -5.80152
26/08/2025 | 12:05:17 | -0.30 | -4.35114
26/08/2025 | 12:05:18 | -0.30 | -4.35114
26/08/2025 | 12:05:19 | -0.30 | -4.35114
26/08/2025 | 12:05:20 | -0.20 | -2.90076
26/08/2025 | 12:05:21 | -0.20 | -2.90076
26/08/2025 | 12:05:22 | -0.20 | -2.90076
26/08/2025 | 12:05:23 | -0.20 | -2.90076
26/08/2025 | 12:05:24 | -0.20 | -2.90076
26/08/2025 | 12:05:25 | -0.20 | -2.90076
26/08/2025 | 12:05:26 | -0.20 | -2.90076
26/08/2025 | 12:05:27 | -0.10 | -1.45038
26/08/2025 | 12:05:28 | -0.20 | -2.90076
26/08/2025 | 12:05:29 | -0.20 | -2.90076
26/08/2025 | 12:05:30 | -0.20 | -2.90076
26/08/2025 | 12:05:31 | -0.20 | -2.90076
26/08/2025 | 12:05:32 | -0.30 | -4.35114
26/08/2025 | 12:05:33 | -0.20 | -2.90076
26/08/2025 | 12:05:34 | -0.20 | -2.90076
26/08/2025 | 12:05:35 | -0.30 | -4.35114
26/08/2025 | 12:05:36 | -0.30 | -4.35114
26/08/2025 | 12:05:37 | -0.30 | -4.35114
26/08/2025 | 12:05:38 | -0.30 | -4.35114
26/08/2025 | 12:05:39 | -0.30 | -4.35114
26/08/2025 | 12:05:40 | -0.30 | -4.35114
26/08/2025 | 12:05:41 | -0.30 | -4.35114
26/08/2025 | 12:05:42 | -0.30 | -4.35114
26/08/2025 | 12:05:43 | -0.30 | -4.35114
26/08/2025 | 12:05:44 | -0.30 | -4.35114
26/08/2025 | 12:05:45 | -0.30 | -4.35114
26/08/2025 | 12:05:46 | -0.30 | -4.35114
26/08/2025 | 12:05:47 | -0.30 | -4.35114
26/08/2025 | 12:05:48 | -0.30 | -4.35114
26/08/2025 | 12:05:49 | -0.30 | -4.35114
26/08/2025 | 12:05:50 | -0.30 | -4.35114
26/08/2025 | 12:05:51 | -0.30 | -4.35114
26/08/2025 | 12:05:52 | -0.30 | -4.35114
26/08/2025 | 12:05:53 | -0.30 | -4.35114
26/08/2025 | 12:05:54 | -0.20 | -2.90076
26/08/2025 | 12:05:55 | -0.20 | -2.90076
26/08/2025 | 12:05:56 | -0.20 | -2.90076
26/08/2025 | 12:05:57 | -0.20 | -2.90076
26/08/2025 | 12:05:58 | -0.20 | -2.90076
26/08/2025 | 12:05:59 | -0.20 | -2.90076
26/08/2025 | 12:06:00 | -0.20 | -2.90076
26/08/2025 | 12:06:01 | -0.20 | -2.90076
26/08/2025 | 12:06:02 | -0.20 | -2.90076
26/08/2025 | 12:06:03 | -0.20 | -2.90076
26/08/2025 | 12:06:04 | -0.20 | -2.90076
26/08/2025 | 12:06:05 | -0.20 | -2.90076
26/08/2025 | 12:06:06 | -0.20 | -2.90076
26/08/2025 | 12:06:07 | -0.20 | -2.90076
26/08/2025 | 12:06:08 | -0.20 | -2.90076
26/08/2025 | 12:06:09 | -0.10 | -1.45038
26/08/2025 | 12:06:10 | -0.20 | -2.90076
26/08/2025 | 12:06:11 | -0.20 | -2.90076
26/08/2025 | 12:06:12 | -0.10 | -1.45038
26/08/2025 | 12:06:13 | -0.10 | -1.45038
26/08/2025 | 12:06:14 | -0.10 | -1.45038
26/08/2025 | 12:06:15 | -0.10 | -1.45038
26/08/2025 | 12:06:16 | -0.10 | -1.45038
26/08/2025 | 12:06:17 | -0.10 | -1.45038
26/08/2025 | 12:06:18 | -0.10 | -1.45038
26/08/2025 | 12:06:19 | -0.10 | -1.45038
26/08/2025 | 12:06:20 | -0.10 | -1.45038
26/08/2025 | 12:06:21 | -0.10 | -1.45038
26/08/2025 | 12:06:22 | -0.10 | -1.45038
26/08/2025 | 12:06:23 | -0.10 | -1.45038
26/08/2025 | 12:06:24 | -0.10 | -1.45038
26/08/2025 | 12:06:25 | -0.10 | -1.45038
26/08/2025 | 12:06:26 | -0.10 | -1.45038
26/08/2025 | 12:06:27 | -0.20 | -2.90076
26/08/2025 | 12:06:28 | -0.20 | -2.90076
26/08/2025 | 12:06:29 | -0.10 | -1.45038
26/08/2025 | 12:06:30 | -0.20 | -2.90076
26/08/2025 | 12:06:31 | -0.10 | -1.45038
26/08/2025 | 12:06:32 | -0.20 | -2.90076
26/08/2025 | 12:06:33 | -0.10 | -1.45038
26/08/2025 | 12:06:34 | -0.20 | -2.90076
26/08/2025 | 12:06:35 | -0.20 | -2.90076
26/08/2025 | 12:06:36 | -0.20 | -2.90076
26/08/2025 | 12:06:37 | -0.20 | -2.90076
26/08/2025 | 12:06:38 | -0.20 | -2.90076
26/08/2025 | 12:06:39 | -0.20 | -2.90076
26/08/2025 | 12:06:40 | -0.20 | -2.90076
26/08/2025 | 12:06:41 | -0.30 | -4.35114
26/08/2025 | 12:06:42 | -0.20 | -2.90076
26/08/2025 | 12:06:43 | -0.20 | -2.90076
26/08/2025 | 12:06:44 | -0.20 | -2.90076
26/08/2025 | 12:06:45 | -0.20 | -2.90076
26/08/2025 | 12:06:46 | -0.30 | -4.35114
26/08/2025 | 12:06:47 | -0.20 | -2.90076
26/08/2025 | 12:06:48 | -0.20 | -2.90076
26/08/2025 | 12:06:49 | -0.20 | -2.90076
26/08/2025 | 12:06:50 | -0.10 | -1.45038
26/08/2025 | 12:06:51 | -0.10 | -1.45038
26/08/2025 | 12:06:52 | -0.10 | -1.45038
26/08/2025 | 12:06:53 | -0.10 | -1.45038
26/08/2025 | 12:06:54 | -0.20 | -2.90076
26/08/2025 | 12:06:55 | -0.20 | -2.90076
26/08/2025 | 12:06:56 | -0.10 | -1.45038
26/08/2025 | 12:06:57 | -0.10 | -1.45038
26/08/2025 | 12:06:58 | -0.10 | -1.45038
26/08/2025 | 12:06:59 | -0.10 | -1.45038
26/08/2025 | 12:07:00 | -0.10 | -1.45038
26/08/2025 | 12:07:01 | -0.10 | -1.45038
26/08/2025 | 12:07:02 | -0.10 | -1.45038
26/08/2025 | 12:07:03 | -0.10 | -1.45038
26/08/2025 | 12:07:04 | -0.10 | -1.45038
26/08/2025 | 12:07:05 | -0.10 | -1.45038
26/08/2025 | 12:07:06 | -0.10 | -1.45038
26/08/2025 | 12:07:07 | -0.10 | -1.45038
26/08/2025 | 12:07:08 | -0.10 | -1.45038
26/08/2025 | 12:07:09 | -0.10 | -1.45038
26/08/2025 | 12:07:10 | -0.10 | -1.45038
26/08/2025 | 12:07:11 | -0.20 | -2.90076
26/08/2025 | 12:07:12 | -0.10 | -1.45038
26/08/2025 | 12:07:13 | -0.20 | -2.90076
26/08/2025 | 12:07:14 | -0.20 | -2.90076
26/08/2025 | 12:07:15 | -0.20 | -2.90076
26/08/2025 | 12:07:16 | -0.20 | -2.90076
26/08/2025 | 12:07:17 | -0.10 | -1.45038
26/08/2025 | 12:07:18 | -0.20 | -2.90076
26/08/2025 | 12:07:19 | -0.10 | -1.45038
26/08/2025 | 12:07:20 | -0.10 | -1.45038
26/08/2025 | 12:07:21 | -0.20 | -2.90076
26/08/2025 | 12:07:22 | -0.10 | -1.45038
26/08/2025 | 12:07:23 | -0.10 | -1.45038
26/08/2025 | 12:07:24 | -0.10 | -1.45038
26/08/2025 | 12:07:25 | -0.10 | -1.45038
26/08/2025 | 12:07:26 | 0.00 | 0
26/08/2025 | 12:07:27 | 0.00 | 0
26/08/2025 | 12:07:28 | 0.10 | 1.45038
26/08/2025 | 12:07:29 | 0.00 | 0
26/08/2025 | 12:07:30 | 0.00 | 0
26/08/2025 | 12:07:31 | 0.00 | 0
26/08/2025 | 12:07:32 | 0.00 | 0
26/08/2025 | 12:07:33 | 0.10 | 1.45038
26/08/2025 | 12:07:34 | 0.10 | 1.45038
26/08/2025 | 12:07:35 | 0.20 | 2.90076
26/08/2025 | 12:07:36 | 0.20 | 2.90076
26/08/2025 | 12:07:37 | 0.30 | 4.35114
26/08/2025 | 12:07:38 | 0.30 | 4.35114
26/08/2025 | 12:07:39 | 0.40 | 5.80152
26/08/2025 | 12:07:40 | 0.50 | 7.2519
26/08/2025 | 12:07:41 | 0.60 | 8.70228
26/08/2025 | 12:07:42 | 0.70 | 10.15266
26/08/2025 | 12:07:43 | 0.80 | 11.60304
26/08/2025 | 12:07:44 | 1.00 | 14.5038
26/08/2025 | 12:07:45 | 1.10 | 15.95418
26/08/2025 | 12:07:46 | 1.20 | 17.40456
26/08/2025 | 12:07:47 | 1.20 | 17.40456
26/08/2025 | 12:07:48 | 1.30 | 18.85494
26/08/2025 | 12:07:49 | 1.40 | 20.30532
26/08/2025 | 12:07:50 | 1.50 | 21.7557
26/08/2025 | 12:07:51 | 1.50 | 21.7557
26/08/2025 | 12:07:52 | 1.50 | 21.7557
26/08/2025 | 12:07:53 | 1.50 | 21.7557
26/08/2025 | 12:07:54 | 1.50 | 21.7557
26/08/2025 | 12:07:55 | 1.50 | 21.7557
26/08/2025 | 12:07:56 | 1.50 | 21.7557
26/08/2025 | 12:07:57 | 1.50 | 21.7557
26/08/2025 | 12:07:58 | 1.50 | 21.7557
26/08/2025 | 12:07:59 | 1.40 | 20.30532
26/08/2025 | 12:08:00 | 1.40 | 20.30532
26/08/2025 | 12:08:01 | 1.40 | 20.30532
26/08/2025 | 12:08:02 | 1.40 | 20.30532
26/08/2025 | 12:08:03 | 1.40 | 20.30532
26/08/2025 | 12:08:04 | 1.40 | 20.30532
26/08/2025 | 12:08:05 | 1.40 | 20.30532
26/08/2025 | 12:08:06 | 1.40 | 20.30532
26/08/2025 | 12:08:07 | 1.40 | 20.30532
26/08/2025 | 12:08:08 | 1.40 | 20.30532
26/08/2025 | 12:08:09 | 1.10 | 15.95418
26/08/2025 | 12:08:10 | 0.40 | 5.80152
26/08/2025 | 12:08:11 | 0.20 | 2.90076
26/08/2025 | 12:08:12 | 0.00 | 0
26/08/2025 | 12:08:13 | -0.10 | -1.45038
26/08/2025 | 12:08:14 | -0.10 | -1.45038
26/08/2025 | 12:08:15 | -0.20 | -2.90076
26/08/2025 | 12:08:16 | -0.20 | -2.90076
26/08/2025 | 12:08:17 | -0.20 | -2.90076
26/08/2025 | 12:08:18 | -0.20 | -2.90076
26/08/2025 | 12:08:19 | -0.20 | -2.90076
26/08/2025 | 12:08:20 | -0.20 | -2.90076
26/08/2025 | 12:08:21 | -0.20 | -2.90076
26/08/2025 | 12:08:22 | -0.20 | -2.90076
26/08/2025 | 12:08:23 | -0.20 | -2.90076
26/08/2025 | 12:08:24 | -0.20 | -2.90076
26/08/2025 | 12:08:25 | -0.20 | -2.90076
26/08/2025 | 12:08:26 | -0.20 | -2.90076
26/08/2025 | 12:08:27 | -0.20 | -2.90076
26/08/2025 | 12:08:28 | -0.30 | -4.35114
26/08/2025 | 12:08:29 | -0.20 | -2.90076
26/08/2025 | 12:08:30 | -0.20 | -2.90076
26/08/2025 | 12:08:31 | -0.30 | -4.35114
26/08/2025 | 12:08:32 | -0.30 | -4.35114
26/08/2025 | 12:08:33 | -0.30 | -4.35114
26/08/2025 | 12:08:34 | -0.30 | -4.35114
26/08/2025 | 12:08:35 | -0.30 | -4.35114
26/08/2025 | 12:08:36 | -0.30 | -4.35114
26/08/2025 | 12:08:37 | -0.30 | -4.35114
26/08/2025 | 12:08:38 | -0.30 | -4.35114
26/08/2025 | 12:08:39 | -0.20 | -2.90076
26/08/2025 | 12:08:40 | -0.20 | -2.90076
26/08/2025 | 12:08:41 | -0.20 | -2.90076
26/08/2025 | 12:08:42 | -0.10 | -1.45038
26/08/2025 | 12:08:43 | -0.10 | -1.45038
26/08/2025 | 12:08:44 | -0.10 | -1.45038
26/08/2025 | 12:08:45 | -0.10 | -1.45038
26/08/2025 | 12:08:46 | 0.00 | 0
26/08/2025 | 12:08:47 | 0.00 | 0
26/08/2025 | 12:08:48 | -0.10 | -1.45038
26/08/2025 | 12:08:49 | -0.10 | -1.45038
26/08/2025 | 12:08:50 | -0.10 | -1.45038
26/08/2025 | 12:08:51 | -0.20 | -2.90076
26/08/2025 | 12:08:52 | -0.20 | -2.90076
26/08/2025 | 12:08:53 | -0.20 | -2.90076
26/08/2025 | 12:08:54 | -0.20 | -2.90076
26/08/2025 | 12:08:55 | -0.10 | -1.45038
26/08/2025 | 12:08:56 | -0.10 | -1.45038
26/08/2025 | 12:08:57 | -0.10 | -1.45038
26/08/2025 | 12:08:58 | -0.10 | -1.45038
26/08/2025 | 12:08:59 | -0.20 | -2.90076
26/08/2025 | 12:09:00 | -0.20 | -2.90076
26/08/2025 | 12:09:01 | -0.20 | -2.90076
26/08/2025 | 12:09:02 | -0.10 | -1.45038
26/08/2025 | 12:09:03 | -0.10 | -1.45038
26/08/2025 | 12:09:04 | -0.20 | -2.90076
26/08/2025 | 12:09:05 | -0.10 | -1.45038
26/08/2025 | 12:09:06 | -0.10 | -1.45038
26/08/2025 | 12:09:07 | -0.10 | -1.45038
26/08/2025 | 12:09:08 | -0.10 | -1.45038
26/08/2025 | 12:09:09 | -0.10 | -1.45038
26/08/2025 | 12:09:10 | -0.10 | -1.45038
26/08/2025 | 12:09:11 | -0.10 | -1.45038
26/08/2025 | 12:09:12 | -0.10 | -1.45038
26/08/2025 | 12:09:13 | 0.00 | 0
26/08/2025 | 12:09:14 | 0.00 | 0
26/08/2025 | 12:09:15 | 0.00 | 0
26/08/2025 | 12:09:16 | 0.10 | 1.45038
26/08/2025 | 12:09:17 | 0.20 | 2.90076
26/08/2025 | 12:09:18 | 0.20 | 2.90076
26/08/2025 | 12:09:19 | 0.30 | 4.35114
26/08/2025 | 12:09:20 | 0.30 | 4.35114
26/08/2025 | 12:09:21 | 0.40 | 5.80152
26/08/2025 | 12:09:22 | 0.50 | 7.2519
26/08/2025 | 12:09:23 | 0.60 | 8.70228
26/08/2025 | 12:09:24 | 0.70 | 10.15266
26/08/2025 | 12:09:25 | 0.90 | 13.05342
26/08/2025 | 12:09:26 | 1.00 | 14.5038
26/08/2025 | 12:09:27 | 1.20 | 17.40456
26/08/2025 | 12:09:28 | 1.40 | 20.30532
26/08/2025 | 12:09:29 | 1.50 | 21.7557
26/08/2025 | 12:09:30 | 1.60 | 23.20608
26/08/2025 | 12:09:31 | 1.70 | 24.65646
26/08/2025 | 12:09:32 | 1.80 | 26.10684
26/08/2025 | 12:09:33 | 1.80 | 26.10684
26/08/2025 | 12:09:34 | 1.90 | 27.55722
26/08/2025 | 12:09:35 | 2.00 | 29.0076
26/08/2025 | 12:09:36 | 2.10 | 30.45798
26/08/2025 | 12:09:37 | 2.20 | 31.90836
26/08/2025 | 12:09:38 | 2.40 | 34.80912
26/08/2025 | 12:09:39 | 2.40 | 34.80912
26/08/2025 | 12:09:40 | 2.50 | 36.2595
26/08/2025 | 12:09:41 | 2.50 | 36.2595
26/08/2025 | 12:09:42 | 2.90 | 42.06102
26/08/2025 | 12:09:43 | 3.00 | 43.5114
26/08/2025 | 12:09:44 | 3.00 | 43.5114
26/08/2025 | 12:09:45 | 3.10 | 44.96178
26/08/2025 | 12:09:46 | 3.20 | 46.41216
26/08/2025 | 12:09:47 | 3.70 | 53.66406
26/08/2025 | 12:09:48 | 4.10 | 59.46558
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

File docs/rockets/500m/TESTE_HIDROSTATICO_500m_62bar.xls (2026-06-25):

DATE | TIME | Press 2
11/06/2026 | 10:18:53 | 0.00
11/06/2026 | 10:18:54 | 0.00
11/06/2026 | 10:18:55 | 0.00
11/06/2026 | 10:18:56 | 0.00
11/06/2026 | 10:18:57 | 0.00
11/06/2026 | 10:18:58 | 0.00
11/06/2026 | 10:18:59 | 0.00
11/06/2026 | 10:19:00 | 0.00
11/06/2026 | 10:19:01 | 0.00
11/06/2026 | 10:19:02 | 0.00
11/06/2026 | 10:19:03 | 0.00
11/06/2026 | 10:19:04 | 0.00
11/06/2026 | 10:19:05 | 0.10
11/06/2026 | 10:19:06 | 0.10
11/06/2026 | 10:19:07 | 0.20
11/06/2026 | 10:19:08 | 0.20
11/06/2026 | 10:19:09 | 0.30
11/06/2026 | 10:19:10 | 0.40
11/06/2026 | 10:19:11 | 0.50
11/06/2026 | 10:19:12 | 0.50
11/06/2026 | 10:19:13 | 0.60
11/06/2026 | 10:19:14 | 0.80
11/06/2026 | 10:19:15 | 0.80
11/06/2026 | 10:19:16 | 1.30
11/06/2026 | 10:19:17 | 1.50
11/06/2026 | 10:19:18 | 1.60
11/06/2026 | 10:19:19 | 1.70
11/06/2026 | 10:19:20 | 2.20
11/06/2026 | 10:19:21 | 2.40
11/06/2026 | 10:19:22 | 2.60
11/06/2026 | 10:19:23 | 2.80
11/06/2026 | 10:19:24 | 3.20
11/06/2026 | 10:19:25 | 3.50
11/06/2026 | 10:19:26 | 3.90
11/06/2026 | 10:19:27 | 4.40
11/06/2026 | 10:19:28 | 5.20
11/06/2026 | 10:19:29 | 5.40
11/06/2026 | 10:19:30 | 5.50
11/06/2026 | 10:19:31 | 5.60
11/06/2026 | 10:19:32 | 5.70
11/06/2026 | 10:19:33 | 5.70
11/06/2026 | 10:19:34 | 5.70
11/06/2026 | 10:19:35 | 5.70
11/06/2026 | 10:19:36 | 5.70
11/06/2026 | 10:19:37 | 5.70
11/06/2026 | 10:19:38 | 5.90
11/06/2026 | 10:19:39 | 6.30
11/06/2026 | 10:19:40 | 6.60
11/06/2026 | 10:19:41 | 7.10
11/06/2026 | 10:19:42 | 7.50
11/06/2026 | 10:19:43 | 8.10
11/06/2026 | 10:19:44 | 8.60
11/06/2026 | 10:19:45 | 9.50
11/06/2026 | 10:19:46 | 10.20
11/06/2026 | 10:19:47 | 10.60
11/06/2026 | 10:19:48 | 11.00
11/06/2026 | 10:19:49 | 11.90
11/06/2026 | 10:19:50 | 12.30
11/06/2026 | 10:19:51 | 12.70
11/06/2026 | 10:19:52 | 13.10
11/06/2026 | 10:19:53 | 13.90
11/06/2026 | 10:19:54 | 14.50
11/06/2026 | 10:19:55 | 14.90
11/06/2026 | 10:19:56 | 15.50
11/06/2026 | 10:19:57 | 16.10
11/06/2026 | 10:19:58 | 17.40
11/06/2026 | 10:19:59 | 18.20
11/06/2026 | 10:20:00 | 18.70
11/06/2026 | 10:20:01 | 19.00
11/06/2026 | 10:20:02 | 20.40
11/06/2026 | 10:20:03 | 21.50
11/06/2026 | 10:20:04 | 22.50
11/06/2026 | 10:20:05 | 23.60
11/06/2026 | 10:20:06 | 25.40
11/06/2026 | 10:20:07 | 26.30
11/06/2026 | 10:20:08 | 27.20
11/06/2026 | 10:20:09 | 28.10
11/06/2026 | 10:20:10 | 30.00
11/06/2026 | 10:20:11 | 30.80
11/06/2026 | 10:20:12 | 31.30
11/06/2026 | 10:20:13 | 31.70
11/06/2026 | 10:20:14 | 32.00
11/06/2026 | 10:20:15 | 32.00
11/06/2026 | 10:20:16 | 32.00
11/06/2026 | 10:20:17 | 32.00
11/06/2026 | 10:20:18 | 34.20
11/06/2026 | 10:20:19 | 36.60
11/06/2026 | 10:20:20 | 38.20
11/06/2026 | 10:20:21 | 39.10
11/06/2026 | 10:20:22 | 40.10
11/06/2026 | 10:20:23 | 42.50
11/06/2026 | 10:20:24 | 43.70
11/06/2026 | 10:20:25 | 45.30
11/06/2026 | 10:20:26 | 46.70
11/06/2026 | 10:20:27 | 49.50
11/06/2026 | 10:20:28 | 50.30
11/06/2026 | 10:20:29 | 51.40
11/06/2026 | 10:20:30 | 52.70
11/06/2026 | 10:20:31 | 54.60
11/06/2026 | 10:20:32 | 55.00
11/06/2026 | 10:20:33 | 55.20
11/06/2026 | 10:20:34 | 55.40
11/06/2026 | 10:20:35 | 56.60
11/06/2026 | 10:20:36 | 58.00
11/06/2026 | 10:20:37 | 59.40
11/06/2026 | 10:20:38 | 60.70
11/06/2026 | 10:20:39 | 63.20
11/06/2026 | 10:20:40 | 63.80
11/06/2026 | 10:20:41 | 64.20
11/06/2026 | 10:20:42 | 64.40
11/06/2026 | 10:20:43 | 64.60
11/06/2026 | 10:20:44 | 64.70
11/06/2026 | 10:20:45 | 64.70
11/06/2026 | 10:20:46 | 57.30
11/06/2026 | 10:20:47 | 52.50
11/06/2026 | 10:20:48 | 47.10
11/06/2026 | 10:20:49 | 45.70
11/06/2026 | 10:20:50 | 44.80
11/06/2026 | 10:20:51 | 44.10
11/06/2026 | 10:20:52 | 43.40
11/06/2026 | 10:20:53 | 43.40
11/06/2026 | 10:20:54 | 43.60
11/06/2026 | 10:20:55 | 43.70
11/06/2026 | 10:20:56 | 43.90
11/06/2026 | 10:20:57 | 44.00
11/06/2026 | 10:20:58 | 44.10
11/06/2026 | 10:20:59 | 44.30
11/06/2026 | 10:21:00 | 44.50
11/06/2026 | 10:21:01 | 44.60
11/06/2026 | 10:21:02 | 44.60
11/06/2026 | 10:21:03 | 44.60
11/06/2026 | 10:21:04 | 45.20
11/06/2026 | 10:21:05 | 47.50
11/06/2026 | 10:21:06 | 48.10
11/06/2026 | 10:21:07 | 48.50
11/06/2026 | 10:21:08 | 48.80
11/06/2026 | 10:21:09 | 50.70
11/06/2026 | 10:21:10 | 51.90
11/06/2026 | 10:21:11 | 53.40
11/06/2026 | 10:21:12 | 54.60
11/06/2026 | 10:21:13 | 55.80
11/06/2026 | 10:21:14 | 56.20
11/06/2026 | 10:21:15 | 56.40
11/06/2026 | 10:21:16 | 56.50
11/06/2026 | 10:21:17 | 56.60
11/06/2026 | 10:21:18 | 57.40
11/06/2026 | 10:21:19 | 59.00
11/06/2026 | 10:21:20 | 61.00
11/06/2026 | 10:21:21 | 63.20
11/06/2026 | 10:21:22 | 63.80
11/06/2026 | 10:21:23 | 64.10
11/06/2026 | 10:21:24 | 64.40
11/06/2026 | 10:21:25 | 64.50
11/06/2026 | 10:21:26 | 64.60
11/06/2026 | 10:21:27 | 64.70
11/06/2026 | 10:21:28 | 64.70
11/06/2026 | 10:21:29 | 64.70
11/06/2026 | 10:21:30 | 64.60
11/06/2026 | 10:21:31 | 64.60
11/06/2026 | 10:21:32 | 64.60
11/06/2026 | 10:21:33 | 64.60
11/06/2026 | 10:21:34 | 64.50
11/06/2026 | 10:21:35 | 64.50
11/06/2026 | 10:21:36 | 64.50
11/06/2026 | 10:21:37 | 64.40
11/06/2026 | 10:21:38 | 64.30
11/06/2026 | 10:21:39 | 64.30
11/06/2026 | 10:21:40 | 64.30
11/06/2026 | 10:21:41 | 64.30
11/06/2026 | 10:21:42 | 64.20
11/06/2026 | 10:21:43 | 64.20
11/06/2026 | 10:21:44 | 64.20
11/06/2026 | 10:21:45 | 64.20
11/06/2026 | 10:21:46 | 64.20
11/06/2026 | 10:21:47 | 64.10
11/06/2026 | 10:21:48 | 64.10
11/06/2026 | 10:21:49 | 64.10
11/06/2026 | 10:21:50 | 64.10
11/06/2026 | 10:21:51 | 64.10
11/06/2026 | 10:21:52 | 64.00
11/06/2026 | 10:21:53 | 64.00
11/06/2026 | 10:21:54 | 64.00
11/06/2026 | 10:21:55 | 64.00
11/06/2026 | 10:21:56 | 64.00
11/06/2026 | 10:21:57 | 64.00
11/06/2026 | 10:21:58 | 63.90
11/06/2026 | 10:21:59 | 63.90
11/06/2026 | 10:22:00 | 63.90
11/06/2026 | 10:22:01 | 63.90
11/06/2026 | 10:22:02 | 63.90
11/06/2026 | 10:22:03 | 63.90
11/06/2026 | 10:22:04 | 63.90
11/06/2026 | 10:22:05 | 63.90
11/06/2026 | 10:22:06 | 63.90
11/06/2026 | 10:22:07 | 63.80
11/06/2026 | 10:22:08 | 63.80
11/06/2026 | 10:22:09 | 63.80
11/06/2026 | 10:22:10 | 63.80
11/06/2026 | 10:22:11 | 63.80
11/06/2026 | 10:22:12 | 63.80
11/06/2026 | 10:22:13 | 63.80
11/06/2026 | 10:22:14 | 63.80
11/06/2026 | 10:22:15 | 63.80
11/06/2026 | 10:22:16 | 63.70
11/06/2026 | 10:22:17 | 63.70
11/06/2026 | 10:22:18 | 63.70
11/06/2026 | 10:22:19 | 63.70
11/06/2026 | 10:22:20 | 63.70
11/06/2026 | 10:22:21 | 63.70
11/06/2026 | 10:22:22 | 63.70
11/06/2026 | 10:22:23 | 63.70
11/06/2026 | 10:22:24 | 63.60
11/06/2026 | 10:22:25 | 63.60
11/06/2026 | 10:22:26 | 63.60
11/06/2026 | 10:22:27 | 63.60
11/06/2026 | 10:22:28 | 63.60
11/06/2026 | 10:22:29 | 63.60
11/06/2026 | 10:22:30 | 63.60
11/06/2026 | 10:22:31 | 63.60
11/06/2026 | 10:22:32 | 63.60
11/06/2026 | 10:22:33 | 63.50
11/06/2026 | 10:22:34 | 63.50
11/06/2026 | 10:22:35 | 63.50
11/06/2026 | 10:22:36 | 63.50
11/06/2026 | 10:22:37 | 63.50
11/06/2026 | 10:22:38 | 63.50
11/06/2026 | 10:22:39 | 63.50
11/06/2026 | 10:22:40 | 63.50
11/06/2026 | 10:22:41 | 63.50
11/06/2026 | 10:22:42 | 63.50
11/06/2026 | 10:22:43 | 63.50
11/06/2026 | 10:22:44 | 63.40
11/06/2026 | 10:22:45 | 63.40
11/06/2026 | 10:22:46 | 63.40
11/06/2026 | 10:22:47 | 63.40
11/06/2026 | 10:22:48 | 63.40
11/06/2026 | 10:22:49 | 63.40
11/06/2026 | 10:22:50 | 63.40
11/06/2026 | 10:22:51 | 63.40
11/06/2026 | 10:22:52 | 63.40
11/06/2026 | 10:22:53 | 63.40
11/06/2026 | 10:22:54 | 63.40
11/06/2026 | 10:22:55 | 63.40
11/06/2026 | 10:22:56 | 63.40
11/06/2026 | 10:22:57 | 63.30
11/06/2026 | 10:22:58 | 63.30
11/06/2026 | 10:22:59 | 63.30
11/06/2026 | 10:23:00 | 63.30
11/06/2026 | 10:23:01 | 63.30
11/06/2026 | 10:23:02 | 63.30
11/06/2026 | 10:23:03 | 63.30
11/06/2026 | 10:23:04 | 63.30
11/06/2026 | 10:23:05 | 63.30
11/06/2026 | 10:23:06 | 63.20
11/06/2026 | 10:23:07 | 63.20
11/06/2026 | 10:23:08 | 63.20
11/06/2026 | 10:23:09 | 63.20
11/06/2026 | 10:23:10 | 63.20
11/06/2026 | 10:23:11 | 63.20
11/06/2026 | 10:23:12 | 63.20
11/06/2026 | 10:23:13 | 63.20
11/06/2026 | 10:23:14 | 63.20
11/06/2026 | 10:23:15 | 63.20
11/06/2026 | 10:23:16 | 63.20
11/06/2026 | 10:23:17 | 63.20
11/06/2026 | 10:23:18 | 63.20
11/06/2026 | 10:23:19 | 63.20
11/06/2026 | 10:23:20 | 63.10
11/06/2026 | 10:23:21 | 63.10
11/06/2026 | 10:23:22 | 63.10
11/06/2026 | 10:23:23 | 63.10
11/06/2026 | 10:23:24 | 63.10
11/06/2026 | 10:23:25 | 63.10
11/06/2026 | 10:23:26 | 63.10
11/06/2026 | 10:23:27 | 63.10
11/06/2026 | 10:23:28 | 63.10
11/06/2026 | 10:23:29 | 63.10
11/06/2026 | 10:23:30 | 63.10
11/06/2026 | 10:23:31 | 63.10
11/06/2026 | 10:23:32 | 63.10
11/06/2026 | 10:23:33 | 63.10
11/06/2026 | 10:23:34 | 63.10
11/06/2026 | 10:23:35 | 63.00
11/06/2026 | 10:23:36 | 63.00
11/06/2026 | 10:23:37 | 63.00
11/06/2026 | 10:23:38 | 63.00
11/06/2026 | 10:23:39 | 63.00
11/06/2026 | 10:23:40 | 63.00
11/06/2026 | 10:23:41 | 63.00
11/06/2026 | 10:23:42 | 63.00
11/06/2026 | 10:23:43 | 63.00
11/06/2026 | 10:23:44 | 63.00
11/06/2026 | 10:23:45 | 63.00
11/06/2026 | 10:23:46 | 63.00
11/06/2026 | 10:23:47 | 63.00
11/06/2026 | 10:23:48 | 63.00
11/06/2026 | 10:23:49 | 63.00
11/06/2026 | 10:23:50 | 62.90
11/06/2026 | 10:23:51 | 62.90
11/06/2026 | 10:23:52 | 62.90
11/06/2026 | 10:23:53 | 62.90
11/06/2026 | 10:23:54 | 62.90
11/06/2026 | 10:23:55 | 62.90
11/06/2026 | 10:23:56 | 62.90
11/06/2026 | 10:23:57 | 62.90
11/06/2026 | 10:23:58 | 62.90
11/06/2026 | 10:23:59 | 62.90
11/06/2026 | 10:24:00 | 62.90
11/06/2026 | 10:24:01 | 62.90
11/06/2026 | 10:24:02 | 62.90
11/06/2026 | 10:24:03 | 62.90
11/06/2026 | 10:24:04 | 62.90
11/06/2026 | 10:24:05 | 62.90
11/06/2026 | 10:24:06 | 62.90
11/06/2026 | 10:24:07 | 62.90
11/06/2026 | 10:24:08 | 62.90
11/06/2026 | 10:24:09 | 62.80
11/06/2026 | 10:24:10 | 62.80
11/06/2026 | 10:24:11 | 62.80
11/06/2026 | 10:24:12 | 62.80
11/06/2026 | 10:24:13 | 62.80
11/06/2026 | 10:24:14 | 62.80
11/06/2026 | 10:24:15 | 62.80
11/06/2026 | 10:24:16 | 62.80
11/06/2026 | 10:24:17 | 62.80
11/06/2026 | 10:24:18 | 62.80
11/06/2026 | 10:24:19 | 62.80
11/06/2026 | 10:24:20 | 62.80
11/06/2026 | 10:24:21 | 62.80
11/06/2026 | 10:24:22 | 62.80
11/06/2026 | 10:24:23 | 62.80
11/06/2026 | 10:24:24 | 62.80
11/06/2026 | 10:24:25 | 62.80
11/06/2026 | 10:24:26 | 62.80
11/06/2026 | 10:24:27 | 62.80
11/06/2026 | 10:24:28 | 62.80
11/06/2026 | 10:24:29 | 62.80
11/06/2026 | 10:24:30 | 62.80
11/06/2026 | 10:24:31 | 62.80
11/06/2026 | 10:24:32 | 62.70
11/06/2026 | 10:24:33 | 62.70
11/06/2026 | 10:24:34 | 62.70
11/06/2026 | 10:24:35 | 62.70
11/06/2026 | 10:24:36 | 62.70
11/06/2026 | 10:24:37 | 62.70
11/06/2026 | 10:24:38 | 62.70
11/06/2026 | 10:24:39 | 62.70
11/06/2026 | 10:24:40 | 62.70
11/06/2026 | 10:24:41 | 62.70
11/06/2026 | 10:24:42 | 62.70
11/06/2026 | 10:24:43 | 62.70
11/06/2026 | 10:24:44 | 62.70
11/06/2026 | 10:24:45 | 62.70
11/06/2026 | 10:24:46 | 62.70
11/06/2026 | 10:24:47 | 62.70
11/06/2026 | 10:24:48 | 62.70
11/06/2026 | 10:24:49 | 62.70
11/06/2026 | 10:24:50 | 62.70
11/06/2026 | 10:24:51 | 62.70
11/06/2026 | 10:24:52 | 62.70
11/06/2026 | 10:24:53 | 62.70
11/06/2026 | 10:24:54 | 62.70
11/06/2026 | 10:24:55 | 62.70
11/06/2026 | 10:24:56 | 62.70
11/06/2026 | 10:24:57 | 62.70
11/06/2026 | 10:24:58 | 62.70
11/06/2026 | 10:24:59 | 62.70
11/06/2026 | 10:25:00 | 62.60
11/06/2026 | 10:25:01 | 62.60
11/06/2026 | 10:25:02 | 62.60
11/06/2026 | 10:25:03 | 62.60
11/06/2026 | 10:25:04 | 62.60
11/06/2026 | 10:25:05 | 62.60
11/06/2026 | 10:25:06 | 62.60
11/06/2026 | 10:25:07 | 62.60
11/06/2026 | 10:25:08 | 62.60
11/06/2026 | 10:25:09 | 62.60
11/06/2026 | 10:25:10 | 62.60
11/06/2026 | 10:25:11 | 62.60
11/06/2026 | 10:25:12 | 62.60
11/06/2026 | 10:25:13 | 62.60
11/06/2026 | 10:25:14 | 62.60
11/06/2026 | 10:25:15 | 62.60
11/06/2026 | 10:25:16 | 62.60
11/06/2026 | 10:25:17 | 62.60
11/06/2026 | 10:25:18 | 62.60
11/06/2026 | 10:25:19 | 62.60
11/06/2026 | 10:25:20 | 62.60
11/06/2026 | 10:25:21 | 62.60
11/06/2026 | 10:25:22 | 62.60
11/06/2026 | 10:25:23 | 62.60
11/06/2026 | 10:25:24 | 62.60
11/06/2026 | 10:25:25 | 62.60
11/06/2026 | 10:25:26 | 62.60
11/06/2026 | 10:25:27 | 62.60
11/06/2026 | 10:25:28 | 62.60
11/06/2026 | 10:25:29 | 62.60
11/06/2026 | 10:25:30 | 62.50
11/06/2026 | 10:25:31 | 62.50
11/06/2026 | 10:25:32 | 62.50
11/06/2026 | 10:25:33 | 62.50
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

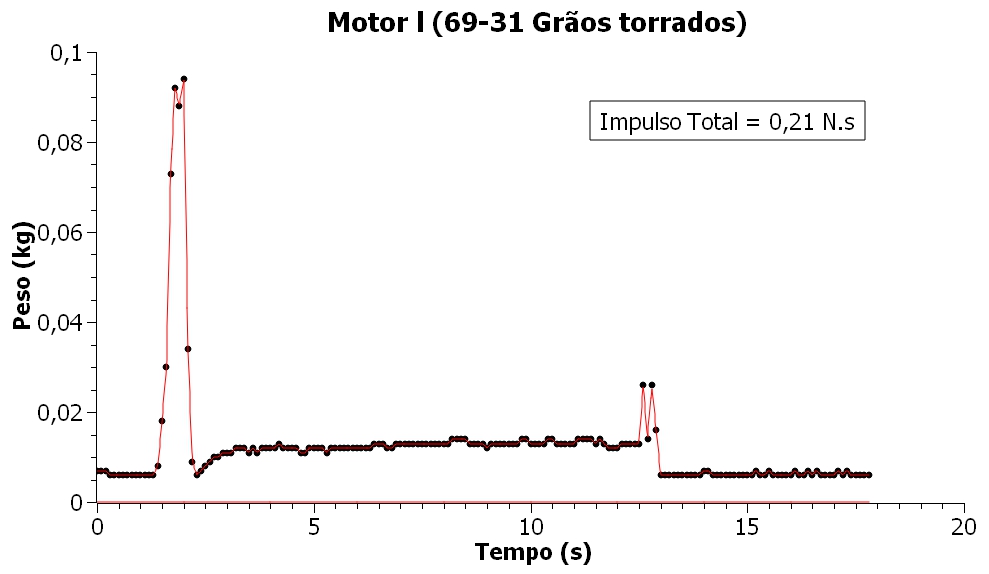
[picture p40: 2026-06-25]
docs/static-tests/motor-i/empuxo_pressao.jpg

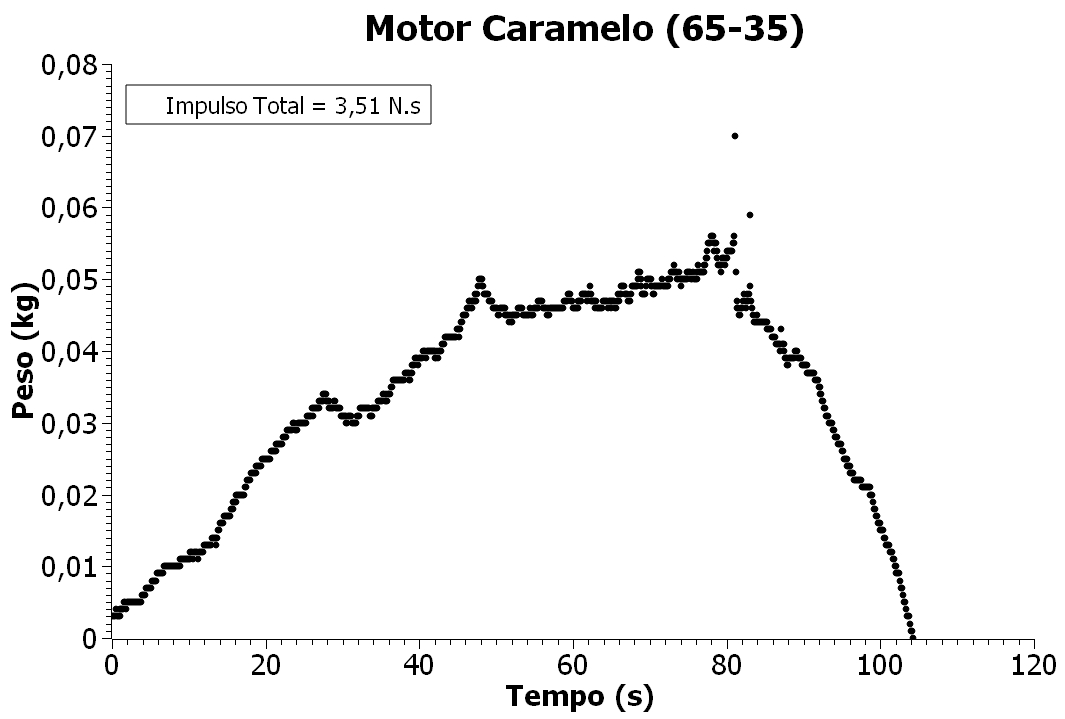
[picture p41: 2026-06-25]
docs/static-tests/motor-caramelo/empuxo_pressao.jpg

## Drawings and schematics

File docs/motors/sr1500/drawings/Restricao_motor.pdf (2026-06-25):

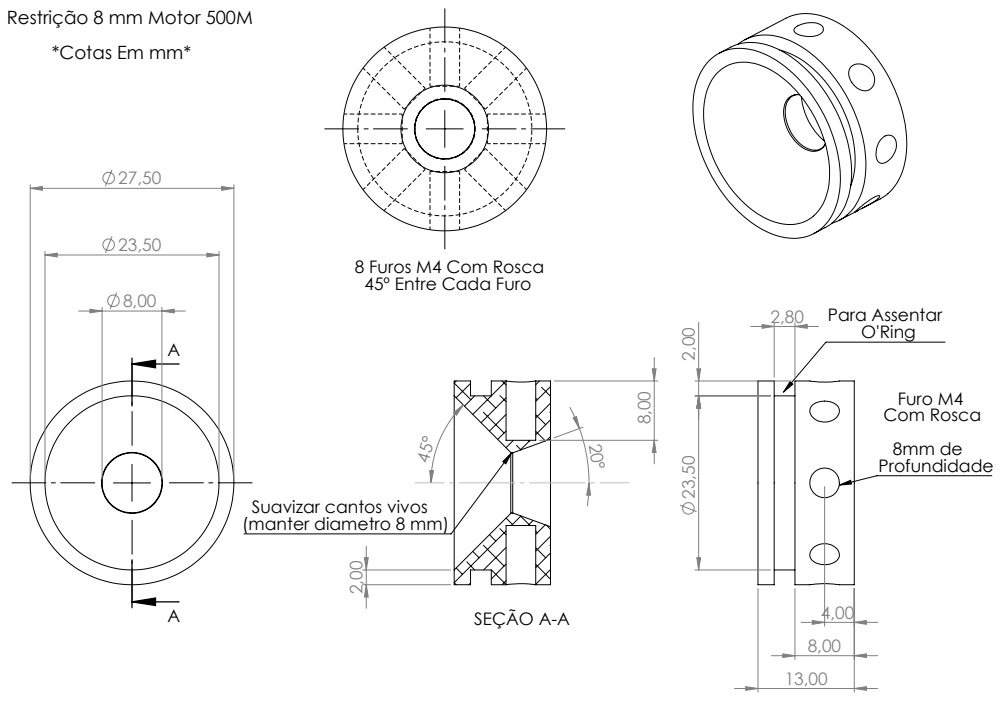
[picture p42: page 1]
Furo M4 Com Rosca 8mm de; Para Assentar; SEÇÃO A-A

Restrição 8 mm Motor 500M
*Cotas Em mm*

8 Furos M4 Com Rosca
45º Entre Cada Furo

Suavizar cantos vivos
(manter diametro 8 mm)

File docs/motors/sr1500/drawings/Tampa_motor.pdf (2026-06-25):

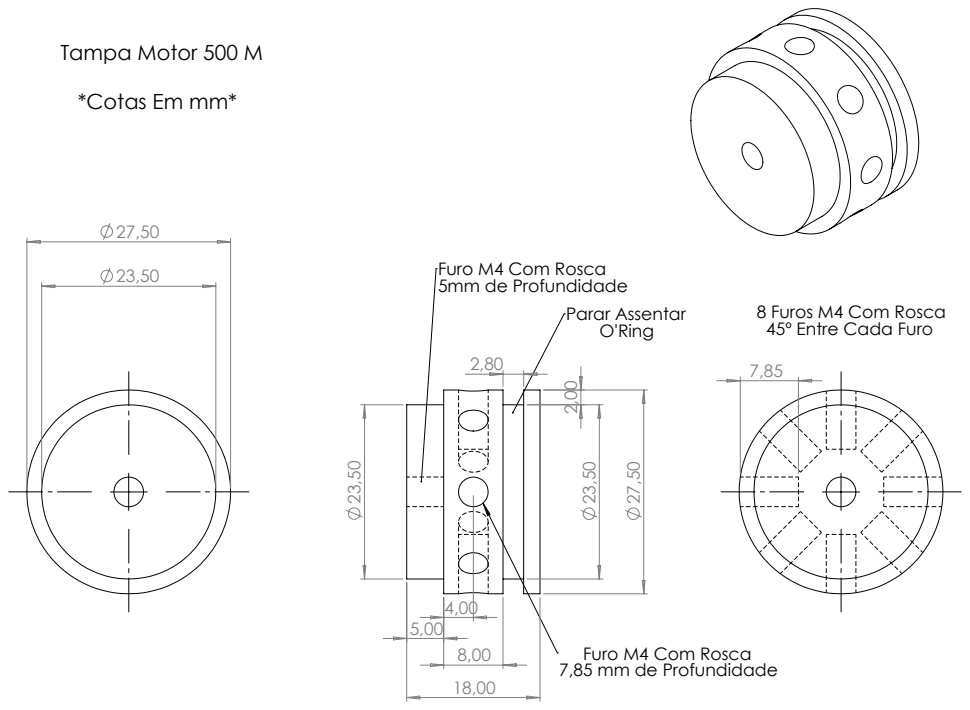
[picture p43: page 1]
Parar Assentar

Tampa Motor 500 M
*Cotas Em mm*

Furo M4 Com Rosca
5mm de Profundidade

8 Furos M4 Com Rosca
45º Entre Cada Furo

7,85 mm de Profundidade

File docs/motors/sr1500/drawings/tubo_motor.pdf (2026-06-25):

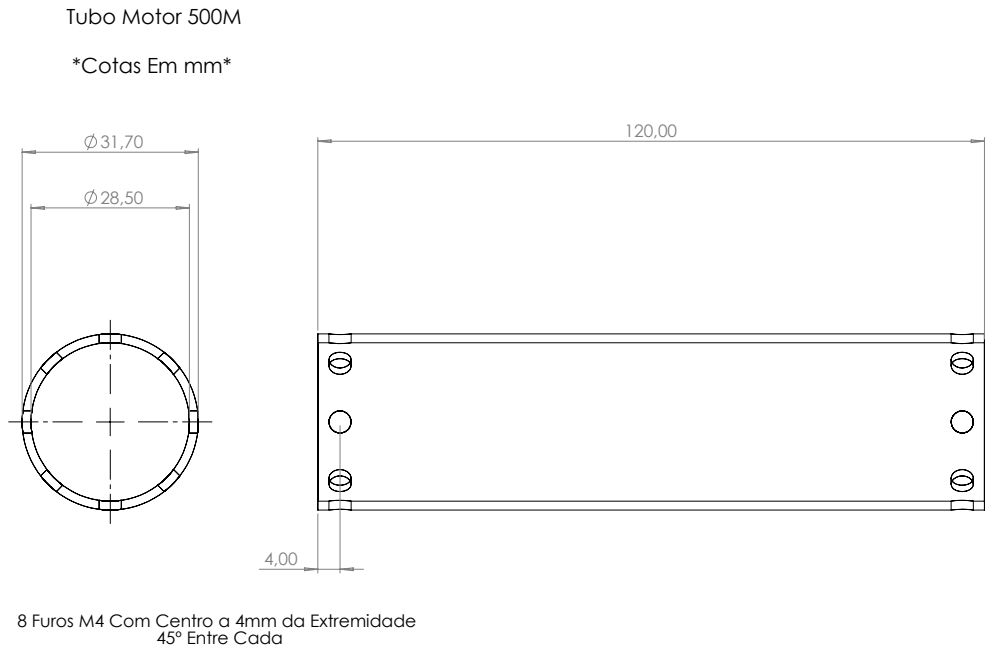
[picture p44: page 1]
45º Entre Cada

Tubo Motor 500M
*Cotas Em mm*

8 Furos M4 Com Centro a 4mm da Extremidade

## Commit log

2026-06-25 feat: importar e organizar arquivos do Drive (Batch 1)
    - Estrutura de diretórios: docs/motors/, docs/rockets/, docs/static-tests/
    - 6 motores: SR21000, SR21000 Inicial, SR1500, 300M, V1, Cardboard
    - 3 foguetes: 500m, 1000m, Commercial
    - CAD (.SLDPRT, .SLDASM, .SLDDRW, .STL, .STEP, .x_t)
    - Simulações OpenMotor (.ric)
    - Dados de teste estático (SD card + gráficos)
    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
    [Acoplamento_motor_fuselagem.SLDPRT, Acoplamento_motor_fuselagem.STL, Base_Molde.SLDPRT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]
2026-06-25 docs: converter docx restantes e copiar arquivos relacionados (Batch 2)
    - 10 docx convertidos para Markdown (reuniões, propelentes, foguetes, ignitor)
    - Planilhas de teste hidrostático (SR21000, 500m)
    - Dados de propelentes (.xlsx)
    - Fluxogramas do ignitor (.pdf)
    - 22 fotos do teste hidrostático do SR21000
    - Novas pastas: propellants/, meetings/, ignitor/
    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
    [TESTE_HIDROSTATICO_500m_62bar.xls, TESTE_HIDROSTATICO_SR21000_88bar.xlsx, dados_propelentes.xlsx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]
2026-06-25 feat: adicionar GIFs de testes de queima e atualizar documentação (Batch 3)
    - 10 vídeos de propelentes convertidos para GIF (320px, 8fps)
    - Total: 155 MB (vs ~2.1 GB dos originais .MOV)
    - teste_queima_2023-06-09.md reescrito com tabela e GIFs embutidos
    - Issue #1 criada: esclarecer Propelente 2 'jeito do coroa'
    - MIGRATION.md atualizado
2026-06-25 docs: adicionar READMEs e finalizar migração (Batch 4)
    - READMEs para motors/, rockets/, propellants/, static-tests/, nozzle/, tools/
    - MIGRATION.md atualizado com status final
    - 208 arquivos em 65 diretórios
    - Migração do Drive concluída
2026-06-25 docs: definir fronteira motor vs analysis no README e AGENTS
    - Adicionada seção 'Fronteira de Responsabilidade' no README.md
    - Adicionada seção 'Fronteira de Responsabilidade' no AGENTS.md
    - Documenta divisão: motor = propulsão, analysis = telemetria
    - Issues #4, #5, #6 criadas para alinhar com equipe
    - Referência a analysis, flight-computer, thrust-stand
2026-06-27 fix(#2): converte HEIC para JPEG e remove originais em hydrostatic
2026-06-27 fix(#2): remove pasta ignitor e adiciona link para repo dedicado
2026-06-27 fix(#2): unifica sr21000-initial no sr21000 e atualiza README
    [Bulkhead.SLDPRT, Montagem.SLDASM, Nozzle.SLDPRT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]
2026-06-27 docs(#2): move nozzle de cimento para archive (ideia não implementada)
    [Base_Molde.SLDPRT, Meio_1_Molde.SLDPRT, Meio_2_Molde.SLDPRT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]
2026-06-28 refactor: reorganiza imagens por motor e padroniza extensões
    - Move docs/imagens/sr1500/ para docs/motors/sr1500/images/
    - Move docs/imagens/sr21000/ para docs/motors/sr21000/images/
    - Remove pasta docs/imagens/ (vazia)
    - Remove pasta docs/motors/sr21000-initial/ (vazia)
    - Padroniza extensões: .JPEG/.PNG/.jpeg → .jpg/.png
    - Atualiza referências em AGENTS.md e MIGRATION.md
2026-06-28 Renomear imagens hidrostaticas para numeracao sequencial (01-16) e remover 3 fotos de radio
    - Removidas IMG_1418.jpg, IMG_1419.jpg, IMG_1420.jpg (fotos de radio Chevrolet DC441, nao pertencem a pasta)
    - Renomeadas 16 imagens de IMG_NNNN.jpg para 01.jpg-16.jpg
    - Renomeacao descritiva pendente devido a bug no sistema de vision (ver issue)
2026-06-28 Renomear imagens do teste hidrostático SR21000 com nomes descritivos em snake_case
    Todas as 16 imagens de docs/motors/sr21000/images/hydrostatic/
    foram renomeadas de numeração sequencial (01-16) para nomes
    descritivos que identificam o conteúdo de cada foto:
    - preparacao_vedacao_oring, inspecao_bocal_e_oring
    - detalhe_bocal_injetor, painel_controle_eletrico
    - bomba_teste_hidrostatico, bomba_haskel_flutrol
    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
2026-06-28 Padronizar nomes de imagens em snake_case e atualizar referências
    Imagens renomeadas:
    - SR21000: Render_SR21000→render_sr21000, Nozzle→nozzle, Bulkhead→bulkhead,
    Grafico_PressaoXTempo→grafico_pressao_tempo, Tubo_400mm→tubo_400mm,
    Render_corte_SR21000→render_corte_sr21000
    - meetings: Dados_iniciais_do_nosso_propelente_→dados_iniciais_propelente
    (removido acento e underline extra)
    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
2026-06-28 remover seção de tabela de motores do README
2026-06-28 Comprimir imagens para <500KB e atualizar AGENTS.md com convenções de imagem
    - 17 imagens comprimidas (1200x, quality 80, strip): 27MB -> 4.6MB
    - Adicionado limite de 500KB por imagem (regra Boas Práticas)
    - Adicionado layout de imagens em docs (HTML tables, 300px)
2026-06-28 Consolidar documentação SR21000 em único relatório
    - Criar SR21000.md com todos os dados do motor (especificações,
    componentes, simulações, teste hidrostático, arquivos)
    - Dados extraídos via visão: dimensões do nozzle, tubo, bulkhead
    - Dados do XLSX: pico de 89.8 bar no teste hidrostático
    - Remover 9 arquivos MD vazios/obsoletos
    - Remover gcode (não versionável)
    - Issues #16-#21 criadas para dados faltantes
2026-06-28 adicionar tabela de competições (LASC 2025 — SR Couto)
2026-06-28 docs(sr21000): reestrutura documento com narrativa cronológica
    - Nova estrutura: Simulação → Projeto → Teste
    - Textos introdutórios explicando decisões de projeto
    - Legendas mais descritivas nas imagens
    - Tabela de próximos passos com status atualizado
    - Mais contexto sobre escolhas de materiais
2026-06-29 docs(sr21000): atualiza status e reestrutura documento
    - Status: 'Em desenvolvimento' → 'Concluído'
    - Imagens reestruturadas (nozzle/design perto de 'Da Ideia Inicial')
    - Desenhos técnicos movidos para antes das tabelas
    - Links de download clicáveis para arquivos CAD
    - Novas seções: Teste Estático e Voo
    - Tabela de dados faltando com issues #16-#22
    - Issue #22 criada para fotos pós-voo
2026-06-29 docs(sr21000): move imagem de performance para seção de resultados
    - openmotor_motor_performance.png agora aparece logo após a tabela de resultados
    - Conexão direta entre números e representação visual
    - Curvas de Desempenho fica apenas com o gráfico x tempo
